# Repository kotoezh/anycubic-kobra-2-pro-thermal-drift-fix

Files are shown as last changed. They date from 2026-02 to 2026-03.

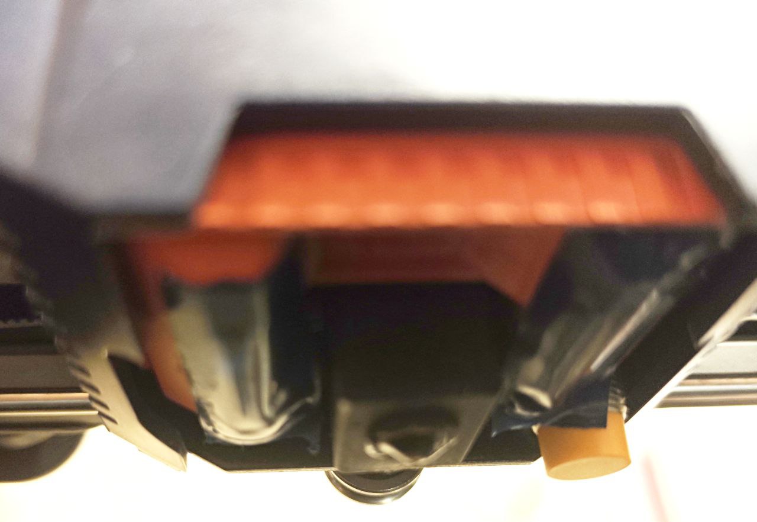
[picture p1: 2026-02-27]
images/photo_tape_sealing_for_calibration.jpg

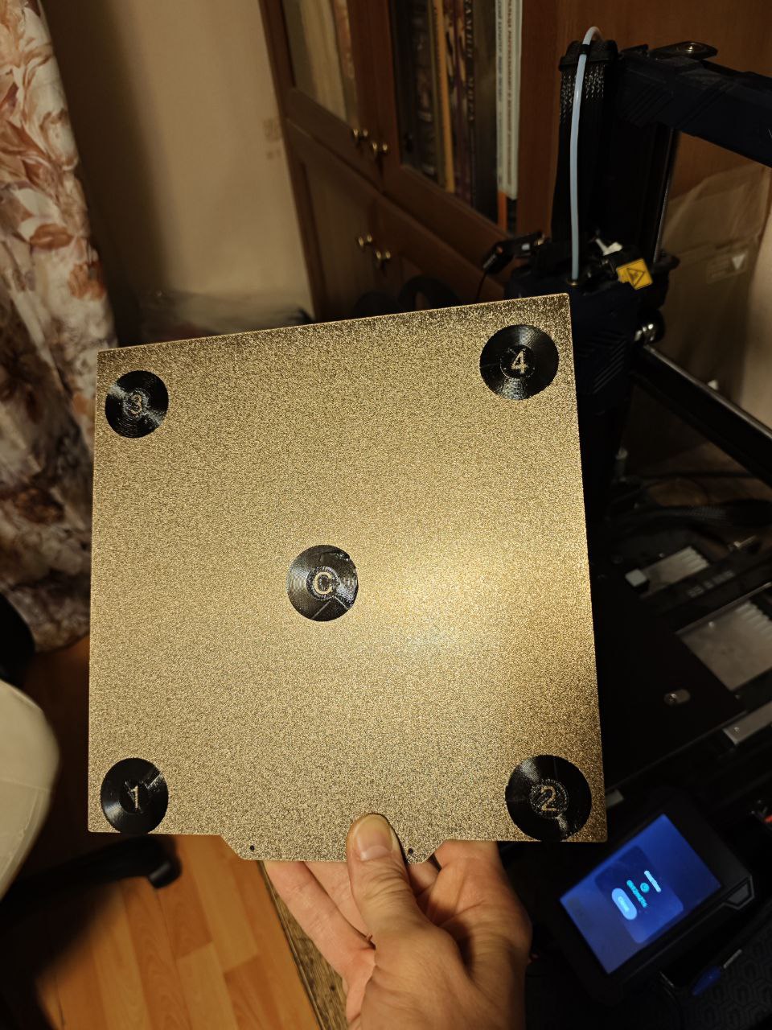
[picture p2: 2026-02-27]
images/photo_test_print_results.jpg

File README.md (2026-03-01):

# anycubic-kobra-2-pro-thermal-drift-fix
Custom Start G-Code for Anycubic Kobra 2 Pro to solve inconsistent Z-offset issues by cooling down inductive sensor before printing starts.

**Update:** Added a hardware-assisted calibration method (the "Tape Hack") to improve bed auto-leveling results and test models to verify Z-offset consistency across the entire bed.

## Problem
### 1. Inconsistent Z-Offset on Restarts
During a print, the sensor gets overheated by the heat rising from the bed and the nozzle. If you start a new print immediately after the previous one, the sensor is still hot. A hot sensor triggers "too high" (too early), causing the nozzle to stay too far from the bed. This results in poor adhesion or printing in the air.
### 2. Distorted Bed Mesh during Auto-Leveling
The same phenomenon affects the auto-calibration process. As the probe moves through its 25 points, it stays near the heated bed for several minutes.
    The sensor starts the calibration "cool" at point #1.
    By the time it reaches the last point, it has absorbed significant heat.
    Because the sensor triggers earlier as it gets warmer, the printer misinterprets this as the bed being "higher" at the end of the path.
This creates a false "warped" mesh in the printer's memory, even if your bed is actually flat, and may affect the adhesion of the first layer.

## Solution
This script implements a "Cold Probe" strategy: it actively cools the sensor at 100mm height before homing, ensuring a stable and repeatable Z-offset regardless of machine temperature.
The base start machine G-Code script is inherited from Anycubic Slicer Next 1.3.6.1 settings for Kobra 2 Pro
Added lines are marked with (+) so you can try implementing this strategy in any other start G-Code

**NB** This solution was physically tested only on the Kobra 2 Pro.

## How to use

### Option 1: Direct Replace (Easiest)
If you are using **Anycubic Slicer Next** (or Orca Slicer), follow these steps:
1. Open your slicer and go to **Printer Settings**.
2. Navigate to the **Machine G-code** tab.
3. Locate the **Machine start G-code** field.
4. Delete the existing code and paste the content of gcode file for your machine (kobra 2 pro, kobra 2/2 neo, kobra 2 max, kobra 2 plus)
5. **Important:** Run a test print and re-calibrate your Z-offset once. Since the homing is now "cold", your previous "hot" Z-offset value may be incorrect.

### Option 2: Manual Modification
If you have a custom start G-code and want to keep it:
1. Find the lines marked with `(+)` in the provided script.
2. Integrate them into your script, ensuring that `G28` (homing) occurs while the sensor is cooled and the nozzle is cold.
3. Make sure to include the `M106 S255` command after the first homing, as the printer firmware may automatically disable the fan.

## Safety Note
Always stay near the printer during the first run after applying this G-code. Ensure the Z-offset is adjusted correctly to prevent the nozzle from touching the print bed.

## Disclaimer & Compatibility

While I have prepared G-code versions for the entire Kobra 2 series (Neo, Pro, Plus, Max) based on their official factory profiles from Anycubic Slicer Next 1.3.6.1, please note:
1. This solution was physically tested only on the Kobra 2 Pro.
2. The versions for Neo, Plus, and Max are provided as-is, based on verified factory start G-code logic. 
3. Use these scripts at your own risk. Always monitor your printer during the first run of a new G-code.
4. G-code in `/models` folder are sliced for Kobra 2 Pro, for printing PETG with bed 75C and nozzle 235C. Don't run them on incompatible machine/filament

## Improved Auto-Leveling Method (The "Tape Hack")
Through testing, I discovered that the standard Auto-Leveling process on the Kobra 2 series also suffers from **cumulative sensor heating**. As the probe moves from point 1 (bottom-left) to point 25 (top-right), it stays close to the heated bed and gradually warms up. This causes the sensor to trigger higher towards the top right corner and is misinterpreted as a higher plate there, even if the plate is totally flat. This may results in an inaccurate "warped" mesh and inconsistent first layer across the plate.

### The Solution:
The print head has a "secret" internal vent designed to cool the inductive sensor (see photo in `/images`). By redirecting all airflow to this vent during calibration, we improve precision of the measurements, even if we cannot change the hardware leveling sequence. 

**Instructions:**
1. **Seal the main vents:** Use masking tape to cover the bottom part-cooling outlets (see photo in `/images`).
3. **Run Calibration:** Start the "Auto-Leveling" from the printer menu. After each measurement firmware forces fan on. Due to sealing main outlets the sensor is cooled more effectively. You can also consider putting a sheet of white paper on the plate to decrease IR radiation effect during the calibration.
4. **Remove Tape:** Once finished, remove the tape, adjust Z-offset and print tests.

*This may allow you to use the entire bed surface with a single, consistent Z-offset.*

## Acknowledgements
This project was developed in collaboration with Gemini (AI), which assisted in technical analysis of thermal drift and G-code optimization.

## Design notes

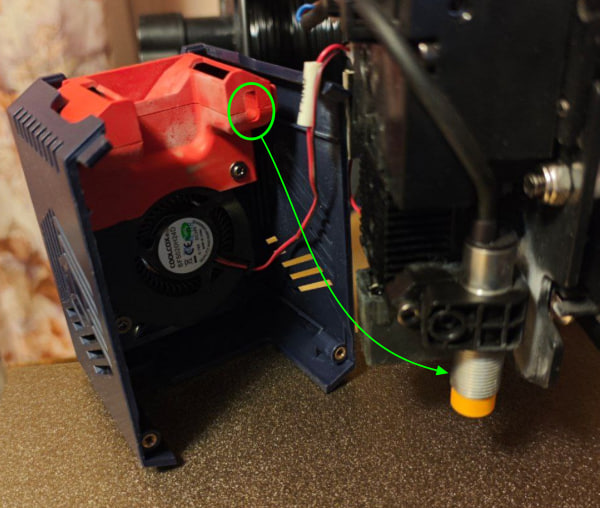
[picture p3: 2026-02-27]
images/photo_sensor_vent_hole.jpg

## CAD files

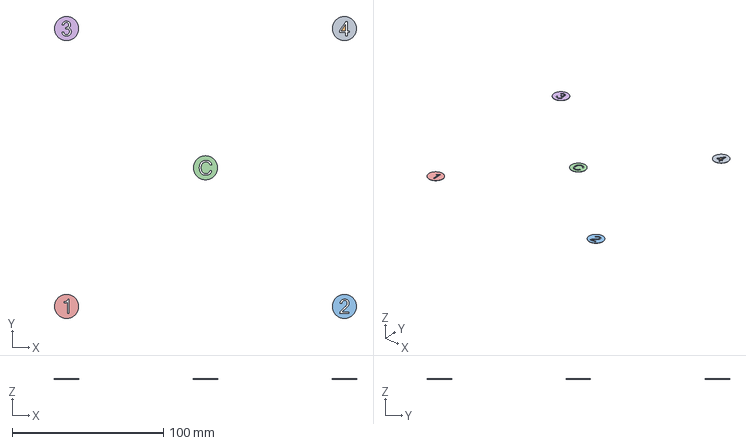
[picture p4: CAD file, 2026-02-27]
models/first_layer_test_concentric.stp
200.0 x 200.0 x 0.24 mm

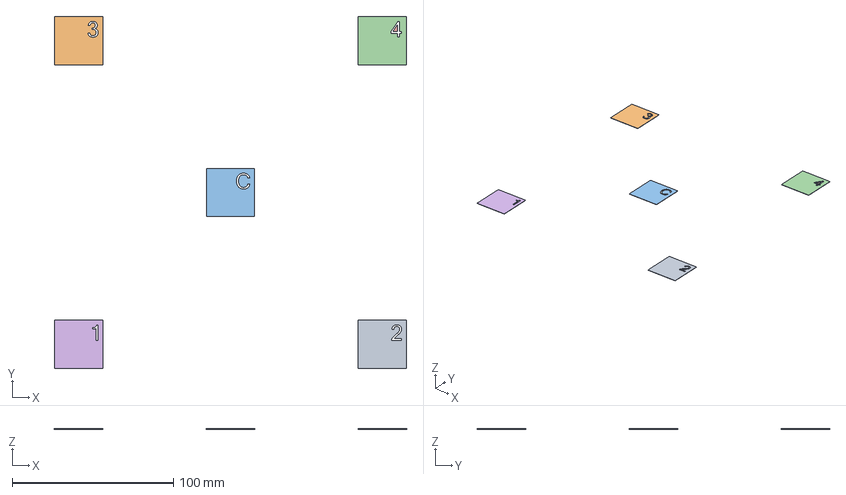
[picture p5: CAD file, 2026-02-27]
models/first_layer_test.stp
218.0 x 218.0 x 0.24 mm

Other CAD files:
models/first_layer_test.3mf
models/first_layer_test_concentric.3mf

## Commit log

2026-02-23 Update README with usage instructions
    Added usage instructions for implementing the Cold Probe strategy in G-code.
2026-02-23 Revise README for clarity on cooling inductive sensor
2026-02-27 Update README with new calibration method
    Added a new hardware-assisted calibration method ('Tape Hack') to improve bed auto-leveling and Z-offset consistency.
2026-02-27 [+] Added images and test models
    [first_layer_test.3mf, first_layer_test.stp, first_layer_test_concentric.3mf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]
2026-03-01 [+] Added start gcode for kobra 2 family printers (k2, k2 neo, k2 puls, k2 max)
